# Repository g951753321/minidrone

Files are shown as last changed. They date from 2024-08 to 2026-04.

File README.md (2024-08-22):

# Minidrone project

This project is a complex project that involves the firmware development, the schematic, and PCB design for a mini drone.

## Firmware development

The firmware development is done using the Zephyr RTOS. The firmware includes the control algorithms for the drone, and the communication with the MicroBlue application.

### Setup Zephyr RTOS

To setup the Zephyr RTOS, follow the instructions in the [Zephyr RTOS documentation](https://docs.zephyrproject.org/latest/getting_started/index.html).

### Project Initialization

To initial the project, clone the repository and run the following commands:

```bash
west init -m https://github.com/g951753321/minidrone.git --mr main minidrone
cd minidrone
west update
```

### Build the project

To build the project, run the following commands:

```bash
west build -b stm32_dev_min minidrone/apps/PID_control
```

The firmware is built for the `stm32_dev_min` board, and the application is `PID_control`.
The output files are located in the `build/zephyr` directory.

## Schematic and PCB design

The schematic/PCB design is done using KiCad. The schematic includes the design of the motor drivers, the microcontroller, and the sensors.

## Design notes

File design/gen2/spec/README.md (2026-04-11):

# miniDrone Gen 2 — Specification Summary

## At a Glance

| Parameter | Value |
|---|---|
| Frame | Quadrotor X-config, 200 x 200 mm max (excl. props) |
| Battery | 3S LiPo (CNHL MiniStar 850mAh 70C) |
| Motors | Brushless 1404 4500KV |
| Propellers | 3 inch |
| Flight Controller | STM32H743VIH6 (Cortex-M7, 480 MHz, FPU-DP) |
| IMU | ICM-42688-P (SPI, 32 kHz, on-PCB center) |
| RC Link | ExpressLRS 2.4 GHz (CRSF, 2-5 ms latency) |
| Config Link | BLE 5.0 (nRF52832 module, phone app) |
| Architecture | Core Module (40x25mm) + Carrier Board (50x50mm)|
| Connector | Castellated pads, 1.27mm pitch, 2x30-pin per edge |
| FW Framework | Zephyr RTOS |

## Specifications

| Parameter | Value |
|---|---|
| Motor | 1404 / 4500 KV  |
| Battery | CNHL 3S 850mAh 70C |
| Pack Voltage | 9.0 - 12.6V |
| AUW | 141 g |
| Max Thrust | 800 g |
| Thrust / Weight | 5.7 : 1 |
| Max Payload | ~100 g (T/W 3.3:1) |
| Hover Time | ~26 min |
| Mixed Flight Time | ~18 min |
| Charging | External balance charger |
| Optional Modules | GPS (2.8g), Camera/VTX (4.5-7g) |

## Sensor Suite

| Sensor | IC | Bus  | Purpose |
|---|---|---|---|
| IMU | ICM-42688-P | SPI1 | Attitude (accel + gyro) |
| Barometer | BMP390 | I2C1 | Altitude hold (> 2 m) |
| Time-of-Flight | VL53L5CX | I2C1 | Altitude hold (< 4 m) |
| Optical Flow | PMW3901 | SPI2 | Position hold |
| Pack ADC | STM32 ADC1  | -- | Pack voltage (30K/10K divider) |
| Cell ADC | STM32 ADC1  | -- | Per-cell voltage via JST-XH balance port |
| Motor Current  | Shunt+OpAmp | ADC3 | Backup stall detect |
| Motor RPM | DSHOT bidir | TIM1 | Per-motor eRPM via bidirectional DSHOT300 |

## Control Architecture

```mermaid
graph TD
    ELRS["ELRS RX<br/>(CRSF 420kbaud)"] --> CP["CRSF Parser"]
    BLE["BLE Module<br/>(115200 baud)"] --> BP["BLE Protocol Parser"]
    CP --> CD["Command Dispatch<br/>(drone_cmd_t)"]
    BP --> CD
    CD --> SM["State Machine<br/>[Calibrate | Diag | Running | Error]"]
    SM --> APID["Angle PID<br/>(1 kHz)"]
    SM --> AltPID["Altitude PID<br/>(50 Hz)"]
    SM --> PosPID["Position PID<br/>(50 Hz)"]
    AltPID --> APID
    PosPID --> APID
    APID --> RPID["Rate PID<br/>(4 kHz)"]
    RPID --> MIX["Motor Mixer"]
    MIX --> DSHOT["DSHOT300 DMA"]
    DSHOT --> M1["M1 FR"]
    DSHOT --> M2["M2 FL"]
    DSHOT --> M3["M3 BR"]
    DSHOT --> M4["M4 BL"]

    IMU["ICM-42688-P<br/>(SPI, 8 kHz)"] --> RPID
    IMU --> APID
    BARO["BMP390<br/>(I2C, 50 Hz)"] --> AltPID
    TOF["VL53L5CX<br/>(I2C, 60 Hz)"] --> AltPID
    OF["PMW3901<br/>(SPI, 100 Hz)"] --> PosPID
```

## Power Architecture

```mermaid
graph LR
    subgraph CARRIER ["Carrier Board"]
        BAT["Battery<br/>3S LiPo<br/>(XT60)"] --> PTC["PTC Fuse<br/>5A / 10A"]
        PTC --> PFET["P-FET Switch<br/>DMP3010LK3<br/>30V"]
        PFET --> LC["LC Filter<br/>4.7uH + 100uF"]
        LC --> VBAT["+VBAT<br/>(ESC / Motors)"]
        LC --> BUCK["TPS63070<br/>Buck<br/>6-13V → 3.3V"]
        BAL["Balance Port<br/>JST-XH"] -.->|"cell taps"| ADC["MCU ADC<br/>cell monitoring"]
        BAL -.->|"external balance charger"| BAT
    end

    subgraph CORE ["Core Module"]
        USB["USB-C<br/>VBUS 5V"] --> ESD["TVS ESD<br/>USBLC6"]
        ESD --> LDO["AP2112K LDO<br/>5V → 3.3V"]
        ESD --> USBPHY["STM32 USB<br/>DFU / CDC"]
        LDO --> PWROR["Power OR"]
        PWROR --> V33["+3V3<br/>(All Digital)"]
    end

    BUCK -->|"carrier 3V3<br/>(via castellated pads)"| PWROR
```

## State Machine

```mermaid
stateDiagram-v2
    [*] --> Calibrate : Power On

    Calibrate --> Diag : success
    Calibrate --> Calibrate : fail (retry)
    Calibrate --> Error : timeout / HW fault

    Diag --> Running : arm (pre-flight pass)
    Diag --> Calibrate : recalibrate cmd

    Running --> Diag : disarm
    Running --> Diag : ELRS failsafe (500 ms)
    Running --> Diag : IMU failure (10 ms)
    Running --> Diag : battery critical
    Running --> Diag : excessive tilt > 60°
    Running --> Diag : motor stall

    Error --> [*] : watchdog reset
```

## Failsafe Summary

| Trigger | Detection Time | Motor Action |
|---|---|---|
| ELRS link loss | 500 ms | Ramp down 200 ms |
| IMU failure | 10 ms | Ramp down 200 ms |
| Battery critical | Per-cell < 3.3V| Ramp down 200 ms |
| Battery cutoff | Per-cell < 3.0V| Immediate off |
| Excessive tilt > 60°  | Immediate | Immediate off |
| Motor stall/overcurrent| 100 ms | Immediate off |

## Gen 1 Issues — All Resolved

| # | Issue | Gen 2 Resolution |
|---|---|---|
| HW-01 | Missing gate pull-downs  | ESC handles gate drive |
| HW-02 | No reverse polarity | P-FET (DMP3010LK3, 30V) |
| HW-03 | No overcurrent | PTC fuse (5A hold / 10A trip) |
| HW-04 | No LC filter | 4.7 uH + 100 uF on battery input |
| HW-05 | No gate resistors | ESC handles internally |
| HW-06 | No ESD protection | TVS on USB-C and SWD |
| HW-07 | DRC violations | 4-layer PCB resolves routing/thermal |
| HW-08 | IMU/BT power sequence | Separate enable; 200 ms delay |
| HW-09 | BOOT0 jumper usability | USB-C DFU via button hold |
| HW-10 | Cannot power off | High-side P-FET clean cutoff |
| HW-11 | Overweight (74 g) | 52-83 g (config dependent, all flyable)  |
| HW-12 | BT/IMU EMI interference  | IMU at center, BLE at edge, GND plane |
| HW-13 | LDO inefficient (45%) | TPS63070 buck-boost on carrier board (88-93%) |

## Purity Boundary

```mermaid
graph LR
    subgraph IN ["Input Shell"]
        CRSF_BE["CRSF Backend<br/>(UART)"]
        BLE_BE["BLE Backend<br/>(UART)"]
        SPI_DRV["SPI Drivers<br/>(IMU, Flash, OF)"]
        I2C_DRV["I2C Drivers<br/>(Baro, ToF)"]
        ADC_HAL["ADC HAL<br/>(Battery, Current)"]
    end

    subgraph CORE ["Pure Core"]
        CRSF_P["CRSF Parser"]
        BLE_P["BLE Parser"]
        CMD["Command Dispatch"]
        SM["State Machine"]
        APID["Angle PID"]
        RPID["Rate PID"]
        MIX["Motor Mixer"]
        ATT["Attitude Est."]
        ALT["Altitude Est."]
        POS["Position Est."]
        BATT["Battery Level"]
        DS_ENC["DSHOT Encoder"]
    end

    subgraph OUT ["Output Shell"]
        DSHOT_HAL["DSHOT DMA"]
        LED_HAL["WS2812B"]
        BB_LOG["Blackbox Flash"]
        USB_DRV["USB CDC/DFU"]
        TELEM["BLE Telemetry"]
    end

    CRSF_BE --> CRSF_P
    BLE_BE --> BLE_P
    SPI_DRV --> ATT
    SPI_DRV --> POS
    I2C_DRV --> ALT
    ADC_HAL --> BATT

    CRSF_P --> CMD
    BLE_P --> CMD
    CMD --> SM
    SM --> APID
    ALT --> APID
    POS --> APID
    ATT --> RPID
    APID --> RPID
    RPID --> MIX
    MIX --> DS_ENC

    DS_ENC --> DSHOT_HAL
    SM --> LED_HAL
    SM --> TELEM
    BATT --> TELEM
```

## Verification Strategy

| Tool | Target | Properties |
|---|---|---|
| **TLA+** | State machine | 13 safety + 4 liveness properties |
| **CBMC** | Pure core C code | 17 bounded model-check properties |
| **Fuzz** | CRSF + BLE parsers | Buffer safety, termination |
| **Ztest**| Full firmware | 20 testable-only properties |
| **HIL**  | Hardware-in-loop | Timing, accuracy, end-to-end |

## Key Design Decisions

1. **ELRS + BLE dual-link** — ELRS for low-latency flight; BLE for config/OTA. Independent.
2. **3S single config** — CNHL 850mAh 70C. Per-cell monitoring via JST-XH balance port.
3. **4-layer PCB** — GND plane fixes Gen 1 EMI; smaller board; ~$2-3 extra/board.
4. **Cascaded PID** — Angle (1 kHz) + rate (4 kHz), far better than Gen 1 single 500 Hz.
5. **Pure core / shell** — All flight math is deterministic, host-testable, formally verifiable.
6. **ICM-42688-P** — 10x lower noise than MPU6050, SPI, 32 kHz. MPU6050 is obsolete.
7. **TPS63070** — Buck regulator for 3S at ~89% efficiency; on carrier board.
8. **Modular core + carrier** — H743 dev module reusable for drones, robotics, and general embedded dev. Castellated pads for zero-weight production or socketed for development.
9. **Per-cell monitoring via JST-XH** — Standard balance connector enables per-cell ADC monitoring AND external balance charging. Imbalance detection refuses arm on damaged batteries.
10. **Bidirectional DSHOT300 + BlueJay** — Per-motor eRPM telemetry at 4 kHz. RPM-based stall detection, dynamic notch filtering, per-motor health monitoring.
11. **GPS + Camera removable** — JST-GH connectors for optional u-blox M10 GPS (2.8g) and HDZero/analog VTX (4.5-7g). Zero weight when not installed.

## Spec Documents

| Document | Contents |
|---|---|
| [features.md](features.md) | Modes, sensors, comms, UI, power, logging, OTA |
| [hardware.md](hardware.md) | MCU, all ICs, power system, PCB stackup |
| [protocols.md](protocols.md) | SPI, I2C, CRSF, BLE binary, DSHOT, USB, ADC |
| [performance.md](performance.md) | Control loops, power budget, flight time, CPU load |
| [safety.md](safety.md) | Protection circuits, failsafe, EMI, ESD, thermal |
| [behavioral.md](behavioral.md) | Invariants, mode contracts, startup, 50 edge cases |
| [mechanical.md](mechanical.md) | Frame, motors, battery, weight, connectors |
| [remote_controller.md](remote_controller.md)| ELRS TX/RX, BLE GATT, OTA update flow |
| [verification.md](verification.md) | 35 provable + 20 testable properties, TLA+/CBMC/Fuzz |

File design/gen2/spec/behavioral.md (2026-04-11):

# Behavioral Specification (Gen 2)

## 1. Behavioral Contract

### 1.1 System Invariants

These conditions must hold true at all times regardless of mode.

| ID | Invariant |
|---|---|
| INV-1 | Motors DSHOT output = 0 (disarmed) unless mode is Running AND armed |
| INV-2 | Battery voltage is sampled at least once per 100 ms |
| INV-3 | Per-cell voltage < 3.0V (cutoff) forces all motors off immediately (scaled by detected cell count) |
| INV-4 | IMU failure detected after 10 ms of no INT1 pulse; motors ramp to 0 over 200 ms, transition to Diag |
| INV-5 | Watchdog timer is refreshed every rate PID loop iteration |
| INV-6 | PID integrator is clamped to prevent windup (both rate and angle loops) |
| INV-7 | Motor DSHOT throttle value never exceeds 2047 |
| INV-8 | Motor current never exceeds 5 A per channel (software cutoff) |
| INV-9 | CRSF failsafe activates if no valid frame received within 500 ms |
| INV-10| Blackbox logging does not block flight-critical loops (async DMA writes) |

### 1.2 Mode Preconditions and Postconditions

#### Calibrate Mode

| Aspect | Contract |
|---|---|
| Precondition  | Drone is powered on; motors are disarmed |
| Precondition  | IMU responds to WHO_AM_I (0x75 = 0x47) |
| Precondition  | Barometer responds to CHIP_ID (0x00 = 0x60) |
| Invariant | Motors remain disarmed for entire duration |
| Postcondition (success) | IMU offsets stored; baro ground reference stored; transition to Diag |
| Postcondition (fail) | Error sent via BLE telemetry; remain in Calibrate; LED red blink |
| Postcondition (timeout) | 5 s timeout; calibration fails; report error |

#### Diag Mode

| Aspect | Contract |
|---|---|
| Precondition  | Calibration completed successfully (offsets valid) |
| Invariant | Motors disarmed unless single-motor test active |
| Invariant | Motor test duration <= 500 ms, one motor at a time |
| Postcondition (arm) | All pre-flight checks pass; transition to Running |
| Postcondition (recalib) | Clear stored offsets; transition to Calibrate |

##### Pre-Flight Checks (must all pass before arming)

| Check | Condition |
|---|---|
| Calibration valid | IMU offsets stored and non-zero |
| Battery sufficient | Per-cell voltage >= 3.3V (above critical)|
| Cells balanced | max-min cell delta < 100 mV |
| ELRS link active | Valid CRSF frame within last 500 ms |
| IMU healthy | INT1 pulses within last 10 ms |
| ESC RPM telemetry alive  | All 4 motors responding to bidir DSHOT (or backup current sense OK) |
| Throttle low | CRSF CH3 < 200 (near minimum) |
| Arm switch off then on | CH5 must transition from disarm to arm |
| Drone level | Tilt < 10 deg from horizontal |

#### Running Mode

| Aspect | Contract |
|---|---|
| Precondition  | All pre-flight checks passed |
| Precondition  | Battery per-cell voltage >= 3.3V (above critical) |
| Precondition  | ELRS link active |
| Invariant | Rate PID loop executes at 4 kHz (+/- 2%) |
| Invariant | Angle PID loop executes at 1 kHz (+/- 5%) |
| Invariant | CRSF stick center produces zero pitch/roll/yaw setpoint |
| Invariant | Throttle minimum produces motor idle (DSHOT 48); PID active |
| Postcondition (disarm)  | Motors ramp to 0 over 200 ms; PID reset; → Diag  |

#### Error Mode

| Aspect | Contract |
|---|---|
| Precondition  | Unrecoverable fault detected (IMU absent, flash corrupt, etc.)|
| Invariant | Motors permanently disarmed |
| Invariant | LED red fast blink |
| Postcondition | Watchdog timeout → MCU reset → retry startup |

### 1.3 Startup Sequence Contract

```
1.  MCUboot validates active image in Slot 0 (signature + CRC)
    - If invalid: attempt swap with Slot 1 or enter DFU mode
2.  Application boots; start watchdog timer (IWDG, 100 ms timeout)
3.  Initialize GPIO (all DSHOT pins LOW; sensor load switch OFF)
4.  Initialize system clock (HSE 25 MHz → PLL1 → 480 MHz);
    configure D-Cache and I-Cache; configure MPU for DMA regions
5.  Initialize USB (CDC + DFU composite device)
6.  Initialize Zephyr shell (USB CDC + BLE NUS backends)
7.  Check SW1 button state:
    - Held > 3 s → enter DFU mode (no further init)
    - Double-press → enter ELRS bind mode (set flag, continue)
8.  Initialize USART1 (CRSF @ 420000 baud)
9.  Initialize USART2 (BLE NUS @ 115200 baud; shell transport active)
10. Start battery ADC + cell monitoring (DMA, 10 Hz)
10a. Validate 3S battery voltage:
     - 9.0-13.1V → 3S valid, continue
     - < 9.0V → no battery or depleted; USB-only power; refuse arm
11. **Enable sensor load switch** (TPS22918 GPIO HIGH); wait 100 ms
12. Initialize SPI1 (IMU); verify WHO_AM_I (up to 3 retries, 100 ms delay)
    - PASS → continue
    - FAIL → enter Error mode
13. Initialize I2C1; verify barometer (BMP390 CHIP_ID)
    - PASS → continue
    - FAIL → enter Error mode (baro required for auto-land)
14. Initialize SDMMC1 (MicroSD); mount FAT32 filesystem
    - FAIL → log warning; continue without blackbox
15. Initialize VL53L5CX (firmware upload, ~300 ms)
    - FAIL → log warning; continue without ToF (altitude hold degraded)
16. Initialize PMW3901 (Product_ID check)
    - FAIL → log warning; continue without OF (position hold disabled)
16a. Check for GPS module on UART4 (wait 2 s for NMEA sentence)
    - Detected → enable GPS features (outdoor position hold, RTH)
    - Not detected → GPS features disabled (no warning, optional module)
17. Call boot_write_img_confirmed() (MCUboot: mark firmware as valid)
17. Initialize flash (JEDEC ID check)
    - FAIL → log warning; continue without blackbox
18. Enter Calibrate mode
```

Note: Steps 15-17 are non-critical sensors. Failure degrades capability but
does not prevent flight. Steps 13-14 are mandatory.

### 1.4 Shutdown Contract

| Trigger | Behavior |
|---|---|
| SW2 power off | P-FET cuts power; no software action |
| Watchdog timeout | MCU reset → full startup sequence |
| Cell voltage < 3.0V  | Motors off immediately, remain in Diag |
| USB DFU mode | Flight disabled; USB active for firmware update |

---

## 2. Interface Definition

### 2.1 Abstract Input Interface

The drone consumes input through an abstract interface, decoupled from any
specific transport. The primary backend is CRSF over ELRS; the secondary is
BLE for configuration commands.

#### Input Commands (Transport-Agnostic)

| Command | Parameters | Valid In |
|---|---|---|
| CMD_ARM | -- | Diag |
| CMD_DISARM | -- | Running |
| CMD_CALIBRATE | -- | Diag |
| CMD_STICK | throttle, yaw, pitch, roll (int16 each) | Running |
| CMD_SET_FLIGHT_MODE| mode (ACRO / ANGLE / ALT_HOLD) | Running |
| CMD_POSITION_HOLD  | enable (bool) | Running |
| CMD_SET_PID_GAIN | loop (RATE/ANGLE), axis (P/R/Y), gain (KP/KI/KD), value (float) | Any |
| CMD_MOTOR_TEST | motor_id (0-3) | Diag |
| CMD_FIND_ME | enable (bool) | Diag |
| CMD_BLACKBOX_DL | offset, length | Diag |
| CMD_BLACKBOX_ERASE | -- | Diag |

#### Input Command Struct

```c
typedef enum {
    CMD_ARM,
    CMD_DISARM,
    CMD_CALIBRATE,
    CMD_STICK,
    CMD_SET_FLIGHT_MODE,
    CMD_POSITION_HOLD,
    CMD_SET_PID_GAIN,
    CMD_MOTOR_TEST,
    CMD_FIND_ME,
    CMD_BLACKBOX_DL,
    CMD_BLACKBOX_ERASE,
} cmd_type_t;

typedef enum {
    FLIGHT_MODE_ACRO,
    FLIGHT_MODE_ANGLE,
    FLIGHT_MODE_ALT_HOLD,
} flight_mode_t;

typedef enum {
    PID_LOOP_RATE,
    PID_LOOP_ANGLE,
} pid_loop_t;

typedef enum {
    PID_AXIS_PITCH,
    PID_AXIS_ROLL,
    PID_AXIS_YAW,
} pid_axis_t;

typedef enum {
    GAIN_KP,
    GAIN_KI,
    GAIN_KD,
} gain_type_t;

typedef struct {
    cmd_type_t type;
    union {
        struct { int16_t throttle; int16_t yaw;
                 int16_t pitch; int16_t roll; }          stick;
        struct { flight_mode_t mode; }                    flight_mode;
        struct { bool enable; }                           position_hold;
        struct { pid_loop_t loop; pid_axis_t axis;
                 gain_type_t gain; float value; }         pid_gain;
        struct { uint8_t motor_id; }                      motor_test;
        struct { bool enable; }                           find_me;
        struct { uint32_t offset; uint32_t length; }      blackbox_dl;
    };
} drone_cmd_t;
```

#### CRSF Backend Mapping

CRSF channels are mapped to `drone_cmd_t` as follows. For channel assignment
details, see [remote_controller.md](remote_controller.md#channel-assignment-edgetx-mixer).
For CRSF frame format and CRC, see [protocols.md](protocols.md).

| CRSF Input | drone_cmd_t |
|---|---|
| CH1-CH4 (sticks) | CMD_STICK { map(172..1811 → signed range) } |
| CH5 (AUX1) low→high | CMD_ARM |
| CH5 (AUX1) high→low | CMD_DISARM |
| CH6 (AUX2) 3-pos | CMD_SET_FLIGHT_MODE { ACRO / ANGLE / ALT_HOLD }|
| CH7 (AUX3) | CMD_POSITION_HOLD { on/off } |
| CH8 (AUX4) | CMD_FIND_ME { on/off } |

#### BLE Backend Mapping

BLE commands use the binary protocol defined in [protocols.md](protocols.md#ble-communication-protocol).
BLE handles configuration commands only (not flight-critical):

| BLE CMD  | drone_cmd_t |
|---|---|
| 0x10 | CMD_SET_PID_GAIN { loop, axis, gain, value } |
| 0x11 | CMD_BLACKBOX_DL { offset, length } |
| 0x12 | CMD_BLACKBOX_ERASE |
| 0x13 | CMD_FIND_ME { enable } |

### 2.2 Abstract Output Interface (Telemetry)

| Telemetry | Parameters | Rate | Mode |
|---|---|---|---|
| TELEM_BATTERY | voltage_mv (uint16) | 1 Hz | All |
| TELEM_CALIB_RESULT | ok (bool) | Once | Calibrate |
| TELEM_IMU | ax,ay,az,gx,gy,gz (int16) | 10 Hz | Diag |
| TELEM_MODE | mode (enum) | On change  | All |
| TELEM_ERROR | error_code (enum) | On event | All |
| TELEM_LOW_BATT | level (WARNING/CRITICAL) | On change  | All |
| TELEM_ALTITUDE | altitude_cm (int32) | 10 Hz | Running |
| TELEM_LINK_STATS | rssi (int8), lq (uint8) | 1 Hz | All |
| TELEM_MOTOR_CURRENT  | current_mA[4] (uint16) | 10 Hz | Running |

Telemetry is sent via two backends simultaneously:
- **BLE**: all telemetry types (for phone app / configurator)
- **CRSF uplink**: battery voltage, attitude, flight mode (for TX OSD display)

### 2.3 Internal Interfaces

#### IMU Driver

| Function | Input | Output | Rate |
|---|---|---|---|
| imu_init() | -- | status (OK / FAIL) | Once |
| imu_read() | -- | ax,ay,az,gx,gy,gz (int16, raw)  | 8 kHz |
| imu_calibrate()  | sample_count | offsets[6] (int16) | Once |
| imu_health() | -- | bool (INT1 received within 10 ms)| On demand|

#### Motor Driver

| Function | Input | Output  | Constraint |
|---|---|---|---|
| motor_set_dshot()  | channel (0-3), throttle (uint16) | -- | throttle <= 2047 |
| motor_all_stop() | -- | -- | Send DSHOT 0 to all |
| motor_ramp_down()  | duration_ms | -- | Async, non-blocking |
| motor_arm_sequence()| -- | -- | DSHOT arm handshake |
| motor_get_rpm() | ch(0-3) | uint16 RPM | From bidir DSHOT eRPM |

#### Battery Monitor (Pack + Per-Cell)

| Function | Input  | Output | Rate |
|---|---|---|---|
| battery_read_pack_mv()| -- | pack voltage in mV (uint16) | 10 Hz |
| battery_read_cell_mv()| cell(0-2)| cell voltage in mV (uint16) | 10 Hz |
| battery_level() | -- | NORMAL/WARNING/CRITICAL/CUTOFF | 10 Hz |
| battery_imbalance_mv()| -- | max_cell - min_cell delta (uint16) | 10 Hz |
| battery_cell_count()  | -- | 1, 2, or 3 (detected at boot) | Once |

#### Motor Health Monitor

| Function | Input  | Output | Rate |
|---|---|---|---|
| motor_current_mA() | ch(0-3)| current in mA (uint16) | 1 kHz |
| motor_stall_check()  | -- | stall_detected (bool) | 100 Hz (RPM-based primary, current backup) |

#### PID Controller (Cascaded)

Rate loop (inner): 3 independent instances (pitch_rate, roll_rate, yaw_rate)
Angle loop (outer): 2 independent instances (pitch_angle, roll_angle)

| Function | Input | Output |
|---|---|---|
| pid_rate_update() | setpoint, gyro_rate, dt | control output (float) |
| pid_angle_update() | setpoint, estimated_angle, dt  | rate setpoint (float) |
| pid_set_gains() | loop, axis, Kp, Ki, Kd | -- |
| pid_reset() | -- | Clear integrator + derivative state |

#### Attitude Estimator

| Function | Input | Output |
|---|---|---|
| attitude_update() | accel[3], gyro[3], dt | pitch, roll, yaw (float, deg) |

Uses complementary filter (alpha = 0.98 gyro, 0.02 accel).
Future: upgrade to Madgwick or Mahony AHRS.

#### Altitude Estimator

| Function | Input | Output |
|---|---|---|
| altitude_update() | baro_pa, tof_mm, dt | altitude_cm (int32)  |

Fusion: ToF used below 2 m (high accuracy); barometer used above 2 m.
Crossfade between 1.5 m and 2.5 m.

#### Position Estimator

| Function | Input | Output |
|---|---|---|
| position_update() | flow_dx, flow_dy, altitude, dt | velocity_x, velocity_y (float, cm/s) |

Optical flow delta scaled by altitude for metric velocity.

#### Motor Mixer

Converts throttle + PID outputs into four DSHOT throttle values.

```
        Front
    FL(CCW) --- FR(CW)
    |               |
    BL(CW)  --- BR(CCW)
         Back
```

| Motor | Ref | Rotation | Equation |
|---|-----|---|---|
| FR | M1  | CW | throttle + pitch_out + roll_out - yaw_out |
| FL | M2  | CCW | throttle + pitch_out - roll_out + yaw_out |
| BR | M3  | CCW | throttle - pitch_out + roll_out + yaw_out |
| BL | M4  | CW | throttle - pitch_out - roll_out - yaw_out |

Output clamping: each motor value clamped to [0, 2047].
Negative values after mixing are set to 0.

### 2.4 Command Acceptance Matrix

Commands received in an invalid mode are silently ignored.

| Command | Calibrate | Diag | Running | Error |
|---|---|---|---|---|
| CMD_ARM | ignore | accept | ignore | ignore |
| CMD_DISARM | ignore | ignore | accept | ignore |
| CMD_CALIBRATE | ignore | accept | ignore | ignore |
| CMD_STICK | ignore | ignore | accept | ignore |
| CMD_SET_FLIGHT_MODE  | ignore | ignore | accept | ignore |
| CMD_POSITION_HOLD | ignore | ignore | accept | ignore |
| CMD_SET_PID_GAIN | accept | accept | accept | ignore |
| CMD_MOTOR_TEST | ignore | accept | ignore | ignore |
| CMD_FIND_ME | ignore | accept | ignore | ignore |
| CMD_BLACKBOX_DL | ignore | accept | ignore | ignore |
| CMD_BLACKBOX_ERASE | ignore | accept | ignore | ignore |

---

## 3. Edge Case Catalog

### 3.1 Communication Edge Cases

| ID | Scenario | Expected Behavior |
|---|---|---|
| EC-01 | CRSF frame CRC mismatch | Frame discarded; use last valid channel data |
| EC-02 | CRSF frame too short (< 4 bytes) | Frame discarded |
| EC-03 | CRSF sync byte wrong | Resync: scan for next 0xC8 |
| EC-04 | CRSF link lost during Running (alt < 2 m) | Failsafe after 500 ms; ramp motors down; → Diag |
| EC-04a| CRSF link lost during Running (alt >= 2 m) | Failsafe after 500 ms; enter AUTO_LAND: descend 0.5 m/s, hold position (OF/GPS), land when ToF < 0.1 m; → Diag |
| EC-05 | CRSF link restored during AUTO_LAND | Hold altitude; wait for user stick input; resume manual control |
| EC-05a| CRSF link restored after landing complete  | Remain in Diag; user must re-arm |
| EC-06 | ELRS packet rate change mid-flight | Transparent: CRSF parser handles variable rates |
| EC-07 | BLE disconnect during Running | No flight action (BLE not flight-critical) |
| EC-08 | BLE and CRSF send conflicting commands | CRSF has priority for flight commands; BLE for config only |
| EC-09 | UART receive buffer overflow (CRSF) | DMA circular buffer; oldest data overwritten; parser resyncs |
| EC-10 | Rapid arm/disarm toggle | 1 s cooldown between arm attempts |
| EC-11 | BLE protocol checksum mismatch | Frame discarded; NACK sent |

### 3.2 Sensor Edge Cases

| ID | Scenario | Expected Behavior |
|---|---|---|
| EC-12 | IMU WHO_AM_I returns wrong ID at boot | Enter Error mode; LED red blink |
| EC-13 | IMU SPI bus error (MISO stuck) | SPI timeout (5 ms); retry 3x; if fail: failsafe |
| EC-14 | IMU data spike (single-sample outlier) | Handled by digital filter (ICM-42688 AAF + firmware LPF) |
| EC-15 | Calibration with drone not level | Offsets will be wrong; user must recalibrate |
| EC-16 | Calibration with drone moving | Variance check; stddev > threshold → fail |
| EC-17 | IMU failure during Running | Detected after 10 ms no INT1; ramp motors down; → Diag |
| EC-18 | Barometer fails during flight | Altitude hold disabled; degrade to angle/acro mode; warn user |
| EC-19 | ToF out of range (> 4 m) | ToF data marked invalid; altitude from baro only |
| EC-20 | Optical flow over featureless surface | SQUAL < 20; position hold disabled; warn user |
| EC-21 | Optical flow fails completely | Position hold disabled; altitude hold still works |

### 3.3 Power Edge Cases

| ID | Scenario | Expected Behavior |
|---|---|---|
| EC-22 | Battery voltage drops below 3.3V (critical) | LED red blink; buzzer rapid; auto-disarm |
| EC-23 | Battery voltage drops below 3.0V (cutoff) | Motors off immediately; remain in Diag |
| EC-24 | Battery voltage recovers above threshold | No auto-transition; user must re-arm manually |
| EC-25 | ADC noise near threshold | Hysteresis: 100 mV gap between enter and exit |
| EC-26 | Battery disconnected while running | Hardware power loss; no software action possible |
| EC-27 | USB connected during flight | USB powers core module only; flight unaffected |
| EC-28 | USB VBUS without battery | Core module powered from USB; motors disabled (no battery = cannot arm) |
| EC-28a| Battery voltage < 6.0V at boot | Treated as no battery or critically depleted; refuse arm |
| EC-28b| Cell imbalance > 100 mV at boot | Refuse arm; warn user; recommend rebalance via external charger |
| EC-28c| Cell imbalance > 200 mV in flight | Critical: ramp motors to 0; → Diag; log event |
| EC-28d| Single cell drops below 3.0V (cutoff) | Motors off immediately; → Diag (even if pack avg > cutoff) |
| EC-28e| Balance connector unplugged (only main connected) | Cell readings = 0 or noise; firmware detects and disables cell-based protection; falls back to pack-only monitoring with warning |

### 3.4 Motor Edge Cases

| ID | Scenario | Expected Behavior |
|---|---|---|
| EC-29 | Motor test held in Diag | Single pulse 500 ms max; ignore until command released |
| EC-30 | Multiple motor test simultaneous | Only first received honored; others ignored |
| EC-31 | Full throttle immediately after arm | Throttle must be low to arm (pre-flight check); after arm, rate limiter: max 100 DSHOT/tick |
| EC-32 | Throttle zero while armed | Motors at idle (DSHOT 48); PID stabilization active  |
| EC-33 | Excessive tilt (> 60 deg) | Motors off immediately; → Diag |
| EC-34 | Motor stall (eRPM = 0 with throttle > 200) | Disarm all motors; → Diag; report error |
| EC-35 | Motor overcurrent (> 5 A) | Affected motor DSHOT = 0; disarm all; → Diag |
| EC-36 | ESC desync (eRPM > 30% off expected) | BlueJay handles internally; FC logs event; if persistent > 200 ms, warn user |
| EC-37 | Prop strike / sudden load | Detected via RPM drop + current spike; if persistent, disarm |
| EC-37a| Bidirectional DSHOT response timeout | Mark motor as no-telemetry; fall back to current sensing for stall detection |
| EC-37b| GCR decode CRC error | Discard reading; use last valid eRPM; counter triggers fallback if persistent |
| EC-37c| All 4 motors lose RPM telemetry | ESC firmware fault: disarm; → Diag; report error |

### 3.5 Mode Transition Edge Cases

| ID | Scenario | Expected Behavior |
|---|---|---|
| EC-38 | Arm with invalid calibration | Reject arm; remain in Diag; send error |
| EC-39 | Arm with low battery (< 3.3V per cell) | Reject arm; remain in Diag |
| EC-39a| Arm with cell imbalance > 100 mV | Reject arm; remain in Diag; suggest recharge |
| EC-40 | Arm with no ELRS link | Reject arm; remain in Diag |
| EC-41 | Arm with throttle not at minimum | Reject arm; remain in Diag |
| EC-42 | Arm with drone tilted > 10 deg | Reject arm; remain in Diag |
| EC-43 | Calibrate during Running | Ignore command |
| EC-44 | DFU mode requested during Running | Ignore (DFU only at boot via SW1) |
| EC-45 | Power on with critical battery (< 3.3V) | Complete startup; enter Diag; refuse arm |
| EC-46 | Flight mode switch during aggressive maneuver| Smooth transition: angle/rate setpoints interpolated over 100 ms |

### 3.6 Blackbox / Flash Edge Cases

| ID | Scenario | Expected Behavior |
|---|---|---|
| EC-47 | Flash full during flight | Circular buffer: overwrite oldest sector |
| EC-48 | Flash write error | Retry once; if fail, disable logging; flight continues |
| EC-49 | Flash erase during flight | Reject: erase only allowed in Diag mode |
| EC-50 | BLE blackbox download during flight | Reject: download only in Diag mode |

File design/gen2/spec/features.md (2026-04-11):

# Feature Specification (Gen 2)

## Design Constraints

| Parameter | Value |
|---|---|
| Body Size Limit | 200 mm (W) x 200 mm (L), excluding propellers |
| Target AUW | 141 g — see [mechanical.md](mechanical.md) |
| Target Flight Time | ~26 min hover |
| Battery | 3S LiPo (CNHL MiniStar 850mAh 70C) |
| Use Environment | Indoor / Outdoor |
| Architecture | Core Module (40x25mm) + Carrier Board (50x50mm) |

## Modular Architecture

The system is split into a reusable **Core Module** and a drone-specific **Carrier Board**.

### Core Module (40 x 25 mm)
- STM32H743VIH6 MCU (Cortex-M7, 480 MHz, 2 MB flash, 1 MB SRAM)
- nRF52832 BLE 5.0 module
- USB-C (DFU, CDC serial, standalone power)
- SWD debug header
- Reset + DFU buttons, power LED, WS2812B status LED
- Can operate standalone (powered from USB) for development

### Carrier Board (50 x 50 mm, drone-specific)
- All flight sensors (IMU, baro, ToF, optical flow)
- ELRS receiver pads
- ESC / motor pads
- Battery management (TPS63070, charger, protection)
- Buzzer, companion computer header
- For hardware details, see [hardware.md](hardware.md)

### Core Module as Dev Board
The core module functions as a standalone development board:
- Plug into USB-C, program via DFU or SWD
- All MCU peripherals exposed on 1.27mm castellated edge pads
- BLE available for wireless debug and configuration
- Design custom carrier boards for other applications (robotics, data loggers, etc.)

## Operating Modes

The drone operates in four distinct modes, transitioned via ELRS command,
BLE command, or hardware button (SW1).

### Mode Overview

| Mode | Purpose | Motors | LED Color |
|---|---|---|---|
| Calibrate | IMU + barometer offset calibration | Off | Yellow breathe |
| Diag | Sensor readout and system check | Off | Blue solid |
| Running | Active flight with PID control | Armed  | Green solid |
| Error | Unrecoverable fault | Off | Red fast blink |

### Mode: Calibrate

Entered on first boot or by user command. The drone must be placed on a flat,
level surface and remain still during calibration.

- Collect N samples of accelerometer, gyroscope, and barometer data
- Compute and store zero-offset for each IMU axis
- Store barometer ground-level reference pressure
- Send calibration result via telemetry (`"calib"`, `"ok"` / `"fail"`)
- Auto-transition to Diag mode on success

### Mode: Diag

Diagnostic mode for pre-flight system verification. Motors remain disarmed.

- Stream live IMU data via telemetry for inspection
- Report battery voltage and cell count
- Verify ELRS link quality (RSSI, LQ)
- Verify BLE link status
- Verify optical flow sensor status
- Verify barometer / ToF altitude sensor status
- Individual motor test via command (brief DSHOT pulse, one at a time)
- Transition to Running mode via arm command
- Transition to Calibrate mode via calibrate command

### Mode: Running

Active flight mode with cascaded PID stabilization loop.

- Cascaded PID: outer angle loop + inner rate loop, active at 1 kHz (rate) / 500 Hz (angle)
- ELRS stick inputs mapped to throttle / yaw / pitch / roll
- Altitude hold mode via barometer + ToF fusion (toggle via AUX channel)
- Position hold mode via optical flow (toggle via AUX channel)
- PID gains adjustable via BLE configuration interface
- Low battery critical: ramp motors to 0 over 200 ms, transition to Diag
- Disarm command transitions back to Diag mode
- **ELRS failsafe auto-land**: if altitude > 2 m, descend at 0.5 m/s and land; if < 2 m, ramp motors to zero. See [safety.md](safety.md#failsafe-conditions)

### Mode: Error

Entered on unrecoverable hardware fault (IMU not detected, flash corrupt, etc.).

- All motors off
- RGB LED red fast blink
- Error code sent via BLE telemetry
- Watchdog timeout resets MCU to retry startup sequence

### State Transitions

```
                   Power On
                      |
                      v
               +-----------+
               | Calibrate |<-----+
               +-----------+      |
                  |  success      | recalibrate cmd
                  |               |
                  |  fail/timeout |
                  |------+        |
                  v      v        |
               +------+ +-------+ |
          +--->| Diag |  | Error | |
          |    +------+--+-------+ |
          |       | arm cmd       |
          |       v               |
          |  +---------+          |
          +--| Running |----------+
   disarm    +---------+
   low batt
   ELRS failsafe
   IMU failure
   excessive tilt
```

## Flight Control

- 4-channel brushless motor control via DSHOT300
- Cascaded PID attitude stabilization (angle + rate loops)
- 6-axis IMU sensor fusion (accelerometer + gyroscope, ICM-42688-P)
- Barometric altitude hold (BMP390 + VL53L5CX fusion)
- Optical flow position hold (PMW3901)
- Configurable PID gain tuning via BLE
- Motor current sensing via shunt resistor + external op-amp on carrier

## Sensors

| Sensor | IC / Module | Interface | Purpose |
|---|---|---|---|
| IMU | ICM-42688-P | SPI1 | Attitude (accel + gyro) |
| Barometer | BMP390 | I2C1 | Altitude hold (> 2 m) |
| Time-of-Flight | VL53L5CX | I2C1 | Altitude hold (< 4 m) |
| Optical Flow | PMW3901 | SPI2 | Position hold |
| Battery ADC | STM32H7 ADC1  | Internal  | Voltage via divider (30K/10K) |
| Motor Current  | Shunt + op-amp| ADC2 | Stall / overcurrent detect |

For IC specifications and placement requirements, see [hardware.md](hardware.md).
For bus protocols and register maps, see [protocols.md](protocols.md).

## Communication

| Link | Purpose | Module / Interface |
|---|---|---|
| ELRS 2.4 GHz | Primary flight control | ELRS Lite RX, UART (CRSF)|
| BLE 5.0 | Config, telemetry, OTA | nRF52832 module (MDBT42Q) |
| USB-C | Programming, debug, charge| STM32H7 native USB 2.0 FS|
| SWD | Debug interface | 4-pin header (SWDIO, SWCLK, GND, 3V3) |

## User Interface

| Component | Type | Purpose |
|---|---|---|
| RGB LED | WS2812B (x1) | Mode / status / battery indicator |
| Buzzer | Passive piezo | Arm beep, low battery alarm, lost model beep |
| Push Button | SW1 (tactile) | Mode cycle / bind / DFU boot |
| Power Switch | SW2 (slide) | Main power on/off |

### RGB LED Behavior per Mode

| Mode | Color | Pattern |
|---|---|---|
| Calibrate | Yellow | Breathe (fade in/out)|
| Diag | Blue | Solid on |
| Running | Green | Solid on |
| Error | Red | Fast blink (5 Hz) |
| Low Batt Warning  | Orange | Blink (2 Hz) |
| Low Batt Critical | Red | Blink (2 Hz) |
| ELRS not linked | Purple| Slow blink (1 Hz) |
| BLE connected | Cyan  | Single flash on connect |

### Buzzer Behavior

| Event | Pattern |
|---|---|
| Arm | Rising two-tone beep |
| Disarm | Falling two-tone beep |
| Low battery warning | Single beep every 2 s |
| Low battery critical| Continuous rapid beep |
| Lost model (BLE cmd)| Loud continuous tone |
| ELRS bind mode | Repeating short beep |

## Power Management

- **3S LiPo** (CNHL MiniStar 850mAh 70C) with per-cell monitoring via JST-XH
- **Cell imbalance detection**: refuse arm if max-min cell delta > 100 mV
- Per-cell threshold scaling (warning, critical, cutoff) — see [safety.md](safety.md)
- Per-motor RPM monitoring (bidirectional DSHOT) + current backup — see [safety.md](safety.md)
- Low battery warning (LED + buzzer + telemetry notification)
- **No onboard charger** — use external balance charger via JST-XH connector
- **GPS** (removable): JST-GH connector for u-blox M10 module — see [hardware.md](hardware.md)
- **Camera / VTX** (removable): power pads + UART for HDZero, analog, or ESP32-CAM — see [hardware.md](hardware.md)
- For power system components, see [hardware.md](hardware.md#power-supply)

## Programming and Debug

| Interface | Connector | Signals |
|---|---|---|
| USB-C | On core module | USB D+, D-, VBUS, CC1, CC2, GND |
| SWD | On core module (4-pin, 1.27mm pitch) | SWDIO, SWCLK, GND, 3V3 |

### Boot Modes

| SW1 Press at Power-On | Mode |
|---|---|
| Not pressed | Normal boot (flash) |
| Held > 3 s | USB DFU bootloader mode |
| Double-press | ELRS bind mode |

## Data Logging (Blackbox)

- **MicroSD card** (FAT32, SDMMC1 4-bit SDIO interface on carrier)
- File format: CSV (human-readable, directly openable in Linux/Excel/Python)
- Each flight creates a new file: `LOG00001.CSV`, `LOG00002.CSV`, etc.
- Logs: timestamp, IMU raw, PID outputs, motor RPM, battery/cell voltage, ELRS inputs
- Log rate: configurable 100 Hz - 1 kHz (~100 KB/s at 1 kHz)
- **Pop out SD card → plug into any PC → read files directly**
- Ring buffer in DTCM (32 KB) absorbs SD write latency spikes; PID loop unaffected
- Erase / format via BLE shell command or USB serial
- Storage: 8 GB card = ~22 hours at 1 kHz (effectively unlimited)

## OTA Firmware Update (MCUboot)

- **MCUboot** secure bootloader with dual-bank swap on H743
- Slot 0 (Bank 1): active firmware; Slot 1 (Bank 2): staging area
- OTA image received via BLE DFU → written to Slot 1 → MCUboot validates + swaps
- **Automatic rollback**: if new firmware crashes before calling `boot_write_img_confirmed()`, watchdog fires and MCUboot reverts to previous image
- Cryptographic validation: SHA-256 + ECDSA image signature
- Fallback: USB-C DFU mode via hardware button hold at boot
- For detailed OTA flow, see [remote_controller.md](remote_controller.md#ota-firmware-update-via-ble)

## BLE Shell (Runtime Command Line)

- **Zephyr shell over BLE NUS** (Nordic UART Service) via nRF52 module
- Connect from any BLE terminal app (nRF Connect, BLESerial nRF, Wible)
- Full command-line interface for runtime configuration and diagnostics:
  - `pid show`, `pid set pitch kp 1.5` — PID tuning
  - `imu read`, `imu calibrate` — sensor diagnostics
  - `motor test 0`, `motor rpm` — motor testing
  - `battery cells` — per-cell voltage readout
  - `blackbox start`, `blackbox stop`, `blackbox erase` — log control
  - `config save`, `config load` — persistent configuration
  - `gps status` — GPS fix info (when GPS module installed)
- Also accessible via USB CDC serial (same Zephyr shell, wired)
- Supplements structured BLE GATT telemetry (shell for debug, GATT for app)

## Expansion

- I2C bus exposed on SWD connector (shared pins) for external sensors
- 2 spare GPIO pads on PCB edge for future use
- MicroSD stores user configuration and waypoint data alongside logs

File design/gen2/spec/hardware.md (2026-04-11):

# Hardware Specification (Gen 2)

## Modular Architecture

The Gen 2 design is split into two boards:

- **Core Module** — MCU, BLE, USB-C, power regulation, flash. Reusable across projects.
- **Carrier Board** — Sensors, ESC, ELRS, battery management. Drone-specific.

Connected via **2x 30-pin castellated pad headers at 1.27 mm pitch**.

```
+-------------------------------+
|       Core Module (40x25mm)   |
|  STM32H743  nRF52  USB-C     |
|  Flash  LDO  SWD  Buttons    |
|  [||||||||||||||||||||||||||] |  ← 2x30 castellated pads (each side)
+-------------------------------+
         ↕ 1.27mm headers (dev) or solder-down (production)
+-------------------------------+
|      Carrier Board (50x50mm)  |
|  IMU  Baro  ToF  OF  ELRS    |
|  ESC pads  Battery  LC filter |
|  LED  Buzzer  Companion hdr   |
+-------------------------------+
```

### Core-to-Carrier Connector

| Parameter | Value |
|---|---|
| Type | Castellated pads (dual-use) |
| Pitch | 1.27 mm |
| Pins | 2x 30-pin, dual-row, two edges = **120 pads total** |
| Dev Mode | Solder 1.27 mm pin headers onto module; plug into sockets on carrier (e.g., Samtec SSQ series) |
| Production Mode | Solder module directly to carrier via castellated pads |
| Mated Height (dev)  | ~8 mm (with socket) |
| Mated Height (prod) | 0 mm (flush solder) |

### Pin Allocation on Connector

| Group | Pins | Signals (exposed on castellated pads) |
|---|---|---|
| SPI1 | 4 | SCK, MISO, MOSI, CS1 |
| SPI2 | 4 | SCK, MISO, MOSI, CS2 |
| SPI4 | 4 | SCK, MISO, MOSI, CS3 |
| I2C1 | 2 | SDA, SCL |
| I2C2 | 2 | SDA, SCL |
| USART1 | 2 | TX, RX |
| USART3 | 2 | TX, RX |
| UART4 | 2 | TX, RX |
| UART7 | 2 | TX, RX |
| TIM1 CH1-4 | 4 | DSHOT / PWM outputs |
| TIM3 CH1-4 | 4 | Aux PWM outputs |
| ADC1 (x4) | 4 | Battery V, Cell1 V, Cell2 V, spare |
| ADC3 (x4) | 4 | Motor current x4 (via op-amps on carrier) |
| SDMMC1 | 7 | CK, CMD, D0-D3, CD (MicroSD on carrier) |
| Sensor Load Switch | 1 | GPIO output (TPS22918 enable) |
| EXTI (x6) | 6 | Interrupt-capable GPIO |
| GPIO (x10) | 10 | General purpose I/O |
| BLE USART2 TX/RX  | 2 | nRF52 passthrough (from core module) |
| nRF52 Reset | 1 | BLE module reset |
| USB D+/D- | 2 | USB passthrough (optional, if carrier needs connector) |
| +3V3 OUT | 4 | Regulated 3.3V from core module LDO |
| +VBAT IN | 4 | Battery voltage input to core module |
| GND | 16 | Ground (distributed for return current) |
| NRST | 1 | MCU reset |
| BOOT0 | 1 | Boot mode select |
| **Total** | **120** | |

## Core Module

### Microcontroller — STM32H743VIH6

| Parameter | Value |
|---|---|
| MCU | STM32H743VIH6 |
| Core | ARM Cortex-M7 (dual-issue, 6-stage pipeline) |
| FPU | **Double-precision** hardware FPU |
| Flash | **2 MB** (dual-bank) |
| SRAM | **1 MB** (DTCM 128K + AXI 512K + SRAM1-4) |
| I-Cache / D-Cache | 16 KB / 16 KB |
| Max Clock | **480 MHz** |
| Package | LQFP-100 (14 x 14 mm) |
| Operating Voltage | 1.62V - 3.6V |
| USB | USB 2.0 FS + **HS** (with internal PHY) |
| ADC | 3x **16-bit** 3.6 Msps |
| DAC | 2x 12-bit |
| Timers | Advanced (TIM1, TIM8), GP (TIM2-5, TIM12-17) |
| DMA | 2x DMA controller + MDMA |
| RNG | Hardware random number generator |

### Core Module Components

| Component | Part | Location |
|---|---|---|
| MCU | STM32H743VIH6 | Center |
| BLE Module | MDBT42Q (nRF52832) | Edge (antenna outward) |
| USB-C Connector | USB 2.0 receptacle | Edge |
| ESD Protection | USBLC6-2SC6 | Near USB-C  |
| LDO (module power) | AP2112K-3.3 (600mA) | Near MCU |
| HSE Crystal | 25 MHz (SMD 2520) | Near MCU |
| LSE Crystal | 32.768 kHz (SMD 3215) | Near MCU |
| SWD Header | 1x4 pin, 1.27mm pitch | Edge |
| Reset Button | Tactile (SW1) | Edge |
| Boot/DFU Button | Tactile (SW2) | Edge |
| Power LED | Green, 0402 | Edge |
| Status LED | WS2812B (x1) | Edge |
| Decoupling | Per STM32H743 datasheet | Near MCU |

### Core Module Power

| Parameter | Value |
|---|---|
| Input Voltage | +3V3 from carrier **or** USB VBUS (5V) |
| Module LDO | AP2112K-3.3 (from USB VBUS) |
| Power OR | Schottky diode OR: carrier 3.3V or LDO output |
| Module Consumption | ~350 mA max (MCU 300mA + BLE 10mA + LED 20mA) |
| Standalone Operation | Yes — powered from USB-C alone (for dev without carrier) |

Note: When on carrier, carrier supplies 3.3V via TPS63070. Module LDO is
bypassed (diode OR, carrier voltage wins). When standalone, USB VBUS powers
LDO → 3.3V for module only.

### Core Module PCB

| Parameter | Value |
|---|---|
| Dimensions | 40 x 25 mm |
| Layers | 4 (Signal / GND / Power / Signal)  |
| Edge Pads | 2x 30-pin castellated, 1.27mm pitch, both long edges |
| Solder Mask | Both sides, matte black |

## Carrier Board (Drone Application)

## IMU — ICM-42688-P

| Parameter | Value |
|---|---|
| Interface | SPI (up to 24 MHz) |
| Accel Range | +/- 16g (configurable) |
| Gyro Range | +/- 2000 deg/s (configurable) |
| Gyro Noise Density  | 2.8 mdps/rtHz |
| Accel Noise Density | 70 ug/rtHz |
| ODR (max) | 32 kHz (gyro), 32 kHz (accel) |
| On-chip FIFO | 2 KB |
| Package | LGA-14 (2.5 x 3.0 mm) |
| Supply | 1.71V - 3.6V |
| Current | 0.8 mA (gyro + accel, low-noise mode) |
| INT1 Pin | Data-ready interrupt to MCU EXTI |
| Decoupling | 100 nF on VDD, 1 uF on VDDIO |

### Placement Requirements

- Mount at PCB center of gravity
- Minimum 5 mm clearance from motor traces and power planes
- Local ground pour stitched with vias beneath IC
- No copper pour on layer directly beneath sensor (reduce stress)

## Barometer — BMP390

| Parameter | Value |
|---|---|
| Interface | I2C (up to 3.4 MHz) |
| I2C Address | 0x77 (SDO = HIGH) |
| Pressure Range | 300 - 1250 hPa |
| Relative Accuracy | +/- 0.03 hPa |
| Absolute Accuracy | +/- 0.5 hPa |
| Temperature Accuracy| +/- 0.5 C |
| ODR | Up to 200 Hz |
| Package | LGA-10 (2.0 x 2.0 mm) |
| Supply | 1.71V - 3.6V |
| Current | 0.7 mA (normal mode) |
| Decoupling | 100 nF on VDD |

### Placement Requirements

- Shield from direct airflow (place under foam or cover with tape)
- Keep away from heat sources (regulator, motor drivers)
- Vent hole in enclosure for pressure equalization

## Time-of-Flight — VL53L5CX

| Parameter | Value |
|---|---|
| Interface | I2C (up to 1 MHz) |
| I2C Address | 0x29 (default) |
| Range | 20 mm - 4000 mm |
| Zones | 4x4 or 8x8 multi-zone |
| Accuracy | +/- 5 mm (typical) |
| Ranging Rate | Up to 60 Hz |
| FoV | 63 deg (diagonal) |
| Package | Module 6.4 x 3.0 x 1.5 mm|
| Supply | 2.8V (from 3.3V via LDO) or 3.3V direct |
| Current | 18 mA (ranging active) |
| INT Pin | Ranging complete interrupt |
| Decoupling | 100 nF + 4.7 uF on AVDD  |

### Placement Requirements

- Mount on bottom side of PCB, facing down
- Clear optical path (no obstructions within 63 deg FoV cone)
- Cover glass must be clean and flush with PCB bottom surface

## Optical Flow — PMW3901

| Parameter | Value |
|---|---|
| Interface | SPI (up to 2 MHz) |
| Resolution | 30 x 30 pixel array |
| Frame Rate | Up to 121 fps |
| Optimal Height | 80 mm - 1 m |
| Motion Output | Delta-X, Delta-Y (int16)  |
| Package | Module ~15 x 20 mm |
| Supply | 1.8V - 3.6V |
| Current | 8 mA (tracking active) |
| Motion Pin | Motion detected interrupt  |
| Decoupling | 100 nF on VDD |

### Placement Requirements

- Mount on bottom side of PCB, facing down
- Lens must have clear view of ground
- Minimum 80 mm altitude for valid readings
- Co-locate with VL53L5CX for fused altitude + position

## BLE Module — MDBT42Q (nRF52832)

| Parameter | Value |
|---|---|
| Chipset | nRF52832 (Cortex-M4F) |
| BLE Version | 5.0 |
| Interface to STM32  | UART (up to 1 Mbps) |
| Antenna | On-module PCB antenna |
| TX Power | -20 to +4 dBm |
| Range | ~30 m (indoor) |
| Package | Module 16 x 10 x 2.2 mm |
| Supply | 1.7V - 3.6V |
| Current | 5 mA (TX), 5.4 mA (RX) |
| Additional Pins | Reset (from STM32 GPIO) |
| Decoupling | 100 nF + 10 uF on VDD |

### Functions

- BLE GATT server for telemetry streaming
- BLE DFU bootloader for OTA firmware updates (both nRF52 and STM32)
- Configuration interface (PID gains, flight parameters)
- Blackbox data download

### Placement Requirements

- Place at PCB edge with antenna facing outward
- Minimum 10 mm from IMU (reduce RF interference on analog sensors)
- Ground plane keepout under antenna area per module datasheet

## ELRS Receiver

| Parameter | Value |
|---|---|
| Module | BetaFPV ELRS Lite RX or HappyModel EP2 |
| Protocol | ExpressLRS 3.x |
| Frequency | 2.4 GHz |
| Packet Rate | 50 / 150 / 250 / 500 Hz |
| Latency | 2 - 5 ms |
| Interface | UART (CRSF protocol, 420000 baud) |
| Supply | 3.3V (or 5V, module dependent) |
| Current | ~40 mA |
| Weight | 0.5 - 0.9 g |
| Antenna | Ceramic chip or wire dipole|
| Size | ~10 x 10 mm (Lite RX) |

### Mounting

- Solder pads: 3V3, GND, TX, RX
- Antenna should be away from motors and carbon fiber frame
- Secure with double-sided tape or solder directly to FC pads

## Motor System

### Brushless Motors — 1404 4500KV

| Parameter | Value |
|---|---|
| Motor Class | 1404 |
| KV Rating | 4500 KV |
| Stator | 14 mm dia x 4 mm height |
| Max Thrust (3S, 3") | ~200 g per motor |
| Weight | ~8.5 g per motor |
| Shaft | 1.5 mm |
| Max Current | 5 A per motor |
| Connector | JST-PH 1.25 mm 3-pin or solder pads |
| Recommended | BetaFPV 1404 4500KV, FlyFishRC Flash 1404 4500KV |

For propeller specs, see [mechanical.md](mechanical.md).

### 4-in-1 ESC

| Parameter | Value |
|---|---|
| Type | 4-in-1 integrated ESC board |
| Firmware | **BlueJay** (required for bidirectional DSHOT300) |
| Protocol | Bidirectional DSHOT300 |
| Continuous Current  | 6 A per channel |
| Burst Current | 10 A per channel |
| MOSFET | Integrated on ESC board |
| Supply | **3S LiPo (9.0 - 12.6V)** |
| Size | ~20 x 20 mm mounting |
| Weight | ~2-3 g |
| Voltage Rating | >= 13V |

Alternative: discrete motor driver ICs (4x DRV8323 or equivalent, up to 60V)
integrated on main PCB if a custom ESC is preferred.

### Motor Layout

| Motor | Label | Position | Rotation | DSHOT Channel |
|---|---|---|---|---|
| M1 | FR | Front Right | CW | TIM1_CH1 |
| M2 | FL | Front Left  | CCW | TIM1_CH2 |
| M3 | BR | Back Right  | CCW | TIM1_CH3 |
| M4 | BL | Back Left | CW | TIM1_CH4 |

## Power Supply

### Battery — 3S LiPo

| Parameter | Value |
|---|---|
| Model | CNHL MiniStar 850mAh 3S 70C |
| Configuration | 3S (3 cells series) |
| Nominal Voltage | 11.1V |
| Full Charge Voltage  | 12.6V |
| Cutoff Voltage | 9.0V (3.0V per cell) |
| Capacity | 850 mAh |
| Discharge Rate | 70C continuous / 140C burst |
| Energy | 9.44 Wh |
| Main Connector | XT60 |
| Balance Connector | JST-XH 4-pin |
| Dimensions | 62 x 25 x 30 mm |
| Weight | ~80 g (with connector) |

### Balance Connector and Cell Monitoring

A JST-XH balance connector exposes individual cell voltages for both
**external balance charging** and **per-cell monitoring**.

| Parameter | Value |
|---|---|
| Connector | JST-XH 4-pin (3S standard) |
| Pinout | GND, CELL1+, CELL2+, CELL3+ (= +VBAT) |
| Position | Carrier board edge, near XT60 connector |
| Standard | Industry-standard LiPo balance port |
| Use 1 | Plug into external balance charger (primary charging method) |
| Use 2 | Per-cell ADC monitoring (always active) |

### Per-Cell Voltage Monitoring

Cell voltages are read via resistor dividers connected to STM32H743 ADC channels.
Only 2 ADC channels are needed: cell 1 directly, cell 2 cumulative (cell 1 + cell 2).
For 3S, cell 3 is computed as `pack_voltage - cell1 - cell2`.

| Cell | Source | ADC Channel | Divider | Max Input | ADC Voltage |
|---|---|---|---|---|---|
| CELL1 | JST-XH pin 2 (cell1+)| ADC1_INx (CELL1) | 10K / 10K (0.5)  | 4.4V | 2.2V |
| CELL2 | JST-XH pin 3 (cell1+cell2 sum)| ADC1_INy (CELL2) | 30K / 10K (0.25) | 8.8V | 2.2V |
| CELL3 | (computed for 3S) | -- | -- | -- | -- |
| Pack | +VBAT | ADC1_INz (VBAT)  | 30K / 10K (0.25) | 13.1V | 3.28V |

Conversion:
```
cell1_mv  = (adc1 * 3300 * 2) / 4095
cell12_mv = (adc2 * 3300 * 4) / 4095          // cumulative cell1 + cell2 voltage
cell2_mv  = cell12_mv - cell1_mv
cell3_mv  = pack_mv - cell12_mv               // 3S only
```

Cell1 and cell2 measured directly via ADC; cell3 computed from pack voltage.

### Cell Monitoring Features

The MCU uses cell voltages for:

| Feature | Description |
|---|---|
| Imbalance detection  | Refuse arm if max-min cell delta > 100 mV |
| Per-cell low voltage | Critical/cutoff thresholds applied per-cell, not just pack |
| Telemetry | Per-cell voltage reported via BLE and CRSF |
| Health logging | Blackbox logs per-cell voltage at 10 Hz |
| Battery age estimate | Track cycle count and voltage sag patterns |

For threshold values, see [safety.md](safety.md#low-battery-thresholds-per-cell-applies-to-1s--2s--3s).

### Battery Voltage Validation

The firmware validates 3S battery voltage at boot:

| Measured Voltage  | State | Action |
|---|---|---|
| 9.0V - 13.1V | 3S OK | Normal operation |
| < 9.0V | No battery / depleted | USB-only power; refuse arm |

Validation runs once at boot before calibration. All battery thresholds
are expressed as per-cell voltages (3.0V cutoff, 3.3V critical, 3.5V warning)
and applied to the 3-cell pack.

### Power Domains

| Domain  | Voltage | Source | Loads |
|---|---|---|---|
| +VBAT | 9.0 - 12.6V | Battery direct (via XT60)| ESC / Motors, VTX power |
| +3V3 | 3.3V | TPS63070 output | MCU, IMU, Baro, ToF, OF, BLE, ELRS, Flash, LED, Buzzer |
| +VUSB | 5.0V | USB-C VBUS | Core module LDO (standalone power), USB peripheral |
| GND | 0V | Common ground | All |

Note: No onboard battery charging. Use an external balance charger via the
JST-XH balance connector for 3S batteries.

### Buck-Boost Regulator — TPS63070

| Parameter | Value |
|---|---|
| Topology | Buck-boost (step up/down) |
| Input Range | **2.0V - 16V** |
| Output | 3.3V (set by resistor divider) |
| Max Output Current | 2 A |
| Efficiency | ~93% (typical, varies with Vin) |
| Switching Frequency  | 2.4 MHz |
| Package | VQFN-14 (3.5 x 3.5 mm) |
| Inductor | 1.5 uH (shielded, low DCR, 3A rated) |
| Input Capacitor | 10 uF x2 MLCC (X5R/X7R, **25V rated**) |
| Output Capacitor | 22 uF x2 MLCC (X5R/X7R) |
| Feedback Divider | R_TOP: 1M, R_BOT: 470K (3.3V out) |

Note: TPS63070 operates in buck mode for 3S (input 9.0-12.6V, always > 3.3V output).

### Battery Charging — External Only

No onboard battery charger. Charging is performed via an external LiPo
balance charger plugged into the JST-XH balance connector. This is the
standard practice for 2S/3S drones and avoids the weight and complexity of
onboard multi-cell charging.

USB-C is still used for:
- Programming (DFU and SWD via separate header)
- Debug serial (USB CDC)
- Powering the core module standalone (without battery)

### USB-C Connector

| Parameter | Value |
|---|---|
| Connector | USB Type-C 2.0 receptacle (mid-mount or SMD) |
| ESD Protection | USBLC6-2SC6 (SOT-23-6) |
| CC Resistors | 2x 5.1K to GND (UFP, device mode) |
| Functions | USB DFU, USB CDC serial, standalone power |

### Power Switch — High-Side P-FET

| Parameter | Value |
|---|---|
| Switch Type | P-channel MOSFET (e.g., **DMP3010LK3**) |
| Vds Rating | **-30V** (sufficient for 3S: 12.6V) |
| Control | SW2 slide switch (gate control) |
| Rds(on) | < 35 mohm |
| Features | Clean power cutoff, no contact resistance issues |
| Status LED | Green LED downstream of switch (power indicator) |

### Reverse Polarity Protection

| Parameter | Value |
|---|---|
| Method | P-channel MOSFET body diode |
| MOSFET | Same DMP3010LK3 (**-30V rated**) |
| Voltage Drop | < 30 mV at load (Rds(on) path) |

### Overcurrent Protection

| Parameter | Value |
|---|---|
| Device | Resettable PTC fuse |
| Rating | **5A hold / 10A trip** |
| Package | 1210 SMD |
| Location | Between battery connector and power switch |

Note: PTC rated for worst-case 3S full-throttle current. 4 motors can draw
~12 A peak; the 10 A trip protects against short circuits while allowing
brief burst peaks (PTC has thermal time constant).

### Decoupling — Core Module

| Capacitor | Value | Package | Purpose |
|---|---|---|---|
| C_VDD (x8) | 100 nF  | 0402 | MCU VDD bypass (each VDD pin)  |
| C_VDDA | 1 uF + 100 nF | 0402 | MCU analog supply |
| C_VCAP (x2) | 2.2 uF  | 0402 | H743 internal LDO (VCAP pins) |
| C_LDO_IN | 10 uF | 0603 | AP2112K input |
| C_LDO_OUT | 10 uF | 0603 | AP2112K output |
| C_BLE | 100 nF + 10 uF | 0402/0603 | nRF52 module VDD |
| C_USB | 100 nF  | 0402 | USB VBUS decoupling |

### Decoupling — Carrier Board

| Capacitor | Value | Package | Purpose |
|---|---|---|---|
| C_IN_BUCK (x2)  | 10 uF | 0805 25V | Buck-boost input |
| C_OUT_BUCK (x2) | 22 uF | 0805 | Buck-boost output |
| C_IMU | 100 nF + 1 uF | 0402 | ICM-42688 VDD + VDDIO |
| C_BARO | 100 nF  | 0402 | BMP390 VDD |
| C_TOF | 100 nF + 4.7 uF | 0402/0603 | VL53L5CX AVDD |

## Data Storage

STM32H743 has 2 MB dual-bank internal flash. Bank 2 (1 MB) is used for
blackbox logging, eliminating the need for external SPI flash.

| Parameter | Value |
|---|---|
| Blackbox Storage | 1 MB (internal flash bank 2)|
| Page Size | 256 bytes (flash word = 32 bytes) |
| Sector Size | 128 KB |
| Endurance | 10K erase cycles per sector |
| Write Speed | ~3.5 MB/s (via internal bus)|

Note: If more blackbox capacity is needed, an external W25Q128 SPI flash
(16 MB) can be added on the carrier board via SPI4. The core module exposes
SPI4 on the castellated pads for this purpose.

## Oscillators (on Core Module)

| Crystal | Frequency | Package | Load Capacitors | Purpose |
|---|---|---|---|---|
| Y1 | 25 MHz (HSE) | SMD 2520-4Pin | 2x 10 pF (0402) | PLL → 480 MHz |
| Y2 | 32.768 kHz (LSE)| SMD 3215-2Pin | 2x 6.8 pF (0402) | USB SOF, RTC |

Note: H743 requires HSE for USB HS PHY. 25 MHz chosen for clean PLL
multiplication to 480 MHz system clock and 48 MHz USB clock.

## PCB — Core Module

| Parameter | Value |
|---|---|
| Dimensions | 40 x 25 mm |
| Layers | 4 (Signal / GND / Power / Signal)  |
| Dielectric | FR4, 1.0 mm total |
| Copper Thickness  | 35 um (1 oz) outer, 17.5 um (0.5 oz) inner |
| Min Track Width | 0.15 mm (6 mil) |
| Min Clearance | 0.15 mm (6 mil) |
| Edge Pads | Castellated half-holes, 1.27 mm pitch |
| Solder Mask | Both sides, matte black |

### Core Module Design Rules

- H743 LQFP-100 at board center; decoupling caps within 2 mm of VDD pins
- VCAP caps immediately adjacent to VCAP1/VCAP2 pins (critical for internal LDO)
- BLE module antenna at board edge with ground keepout
- USB-C at short edge for easy access
- SWD and buttons at opposite short edge
- 25 MHz HSE crystal within 10 mm of OSC_IN/OSC_OUT
- Continuous GND plane on L2

## PCB — Carrier Board

| Parameter | Value |
|---|---|
| Dimensions | 50 x 50 mm (max) |
| Layers | 4 (Signal / GND / Power / Signal)  |
| Dielectric | FR4, 1.6 mm total |
| Copper Thickness  | 35 um (1 oz) outer, 17.5 um (0.5 oz) inner |
| Min Track Width | 0.15 mm (6 mil) |
| Mounting Holes | 4x M2 at 20 x 20 mm pattern (ESC stack) |
| Module Socket | 2x 30-pin SMD socket pads, 1.27mm pitch |

### Carrier Board Track Width Classes

| Width | Typical Use |
|---|---|
| 0.15 mm | Fine signal (SPI, I2C, GPIO) |
| 0.25 mm | Standard signal |
| 0.50 mm | 3.3V rail (up to 1 A) |
| 1.50 mm | Per-motor power trace (up to 5 A) |
| **Copper pour** | **Battery main +VBAT / GND (>5 A)**  |

Battery rail (+VBAT, GND) must use **copper pours on L1 + L4** stitched with
power vias every 2-3mm. Do not use single traces for battery or ESC input —
3S at full throttle draws up to 20 A peak (4 × 5 A).

### Carrier Sensor Power Switch

| Parameter | Value |
|---|---|
| Device | TPS22918 load switch (SOT-23-5) |
| Control | STM32 GPIO (active high) |
| Load | IMU, Baro, ToF, OF (all 3.3V sensors) |
| Max Current | 500 mA (TPS22918 rated 2A) |
| Purpose | H743 boots first, then enables sensor power after 100 ms |

This fixes Gen 1 HW-08 (IMU/BT power sequence) definitively. Sensors
don't see power spikes during MCU boot or regulator startup.

### Carrier Board Design Rules

- Core module socket at board center-top
- IMU (ICM-42688-P) at board center (near CG)
- Minimum 10 mm between module BLE antenna and IMU
- Battery/ESC power: copper pour on L1 + L4, **not single traces**
- TPS63070 + LC filter near XT60 connector
- Sensor power via TPS22918 load switch (GPIO-controlled)
- Barometer covered with foam; isolated from motor airflow
- GPS + camera connectors at board edge (JST-GH)
- Companion computer header at board edge
- ToF + Optical Flow on bottom side, facing down

### Carrier GPS Connector (Removable Module)

| Parameter | Value |
|---|---|
| Connector | JST-GH 4-pin, 1.25 mm pitch |
| Signals | 3V3, GND, TX (UART4), RX (UART4)  |
| Baud Rate | 38400 (default, configurable) |
| Protocol | NMEA / UBX (auto-detect) |
| Recommended Module| HGLRC M100 Mini (2.8g, u-blox M10, 15x15mm) |
| Alternative | Flywoo GM10 Mini V3 (3.5g, M10 + compass, 20x20mm) |
| Mounting | Velcro or 3D-printed pylon on top of frame |

When GPS is not installed, the connector adds <0.3g. The firmware auto-detects
GPS presence (NMEA sentence received within 2s of boot). If no GPS is detected,
GPS-dependent features (position hold outdoor, RTH) are disabled gracefully.

### Carrier Camera / VTX Connector (Removable Module)

| Parameter | Value |
|---|---|
| Power Pads | +VBAT (direct battery, for VTX), GND |
| Signal Connector  | JST-GH 3-pin: 3V3, TX (UART3), RX (UART3) |
| UART Purpose | VTX control (SmartAudio / MSP DisplayPort) |
| Recommended | HDZero Whoop Lite VTX (4.5g) + Nano90 camera (2.5g) = 7g total |
| Alternative | Analog AIO (Caddx Ant Lite, ~3g total) |
| Alternative | ESP32-CAM (WiFi streaming to phone, ~5g) |
| Mounting | VTX on frame top plate; camera on front tilt mount |

The VTX draws power directly from +VBAT (9-12.6V, within HDZero/analog VTX input range).
The UART provides SmartAudio control (change channel, power) or MSP DisplayPort
for OSD overlay. When no VTX is installed, the pads add <0.2g.

### Carrier Companion Computer Header

| Parameter | Value |
|---|---|
| Connector | 1x4 pin header, 2.54 mm pitch |
| Signals | 3V3, GND, TX (UART7), RX (UART7)  |
| Baud Rate | Configurable (default 921600) |
| Purpose | Future RPi Zero / ESP32 companion  |
| Protocol | MAVLink or custom binary |

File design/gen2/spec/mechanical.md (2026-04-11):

# Mechanical Specification (Gen 2)

## Design Constraints

| Parameter | Value |
|---|---|
| Max Body Size | 200 mm (W) x 200 mm (L), excluding propellers |
| Target AUW | 141 g |
| Configuration | Quadrotor (X-config) |
| Use Environment | Indoor / calm outdoor |

## Frame

| Parameter | Value |
|---|---|
| Configuration | Quadrotor X-frame |
| Material | 3D-printed (TPU/PLA) or carbon fiber plate |
| Motor-to-motor | 130 - 150 mm (diagonal) |
| Arm Width | 8 - 10 mm |
| Arm Thickness | 3 - 4 mm |
| Center Stack | 20 x 20 mm M2 mounting pattern (standard FC/ESC stack) |
| Prop Guard | Optional snap-on TPU guards |

### Frame Layout (Top View)

```
             200 mm max (body)
        +-------------------------+
        |                         |
        |    FL            FR     |     Prop circle (76 mm / 3")
        |     \   ______   /     |     extends beyond body
        |      \ | PCB  | /      |
        |       \| 50x50|/       |
        |        |______|        |
        |       /        \       |
        |      /          \      |
        |    BL            BR    |
        |                         |
        +-------------------------+
```

### Frame Options

| Option | Material | Weight | Pros | Cons |
|---|---|---|---|---|
| A | 3D-printed PLA | ~8 g | Easy to iterate, cheap | Brittle, heavier |
| B | 3D-printed TPU | ~6 g | Flexible, crash resistant | Less rigid, slight vibration |
| C | CF plate (1 mm)| ~5 g | Lightest, stiffest | Harder to manufacture, RF blocking |
| D | PCB-integrated | 0 g | No separate frame needed | PCB must be large enough for arms |

Recommended: **Option B (TPU)** for development, **Option C (CF)** for final version.

If PCB is designed as a full unibody (Option D), arms extend from PCB edges
with motor pads at tips. This eliminates frame weight entirely but limits
PCB shape to the airframe outline.

## Motor Layout

```
        Front
    FL -------- FR
    |            |
    |    PCB     |
    |   (stack)  |
    BL -------- BR
         Back
```

For motor labels (M1-M4), rotation directions, and DSHOT channel assignments,
see [hardware.md](hardware.md#motor-layout).

## Propellers

| Parameter | Value |
|---|---|
| Size | 76 mm (3 inch) |
| Blade Count | 2-blade or 3-blade |
| Material | Polycarbonate |
| Mounting | Press-fit on 1 mm shaft |
| Weight | ~1 g per prop (2-blade) |
| Recommended | HQProp 3x1.5x3 or Gemfan 3018 |

Note: 2.5" props (65 mm) are an alternative for tighter body constraint.
Trade-off: less thrust but fits more easily within 200 mm body limit.

## Motor Specifications

For motor electrical specs (KV, current, thrust), see
[hardware.md](hardware.md#brushless-motors--1404-4500kv).

| Motor Class | Shaft | Weight/Motor |
|---|---|---|
| 1404 | 1.5 mm  | ~8.5 g |

## Battery

For battery electrical specs, see [hardware.md](hardware.md#battery--3s-lipo).

| Model | Capacity | Dimensions (mm) | Weight |
|---|---|---|---|
| CNHL MiniStar 3S | 850 mAh | 62 x 25 x 30 | ~80 g  |

### Battery Mounting

Battery mounts underneath the PCB (center of gravity aligned with thrust center).
Secured by:
- Silicone rubber band (lightweight, quick-swap)
- Or 3D-printed battery tray integrated into frame
- XT60 connector accessible from rear for easy swap
- Battery bay must accommodate 62 x 25 x 30 mm

## Weight Budget

### Common Components

| Component | Count | Unit Weight (g) | Total (g) |
|---|---|---|---|
| Core + Carrier PCBs | 2 | - | 12 |
| 4-in-1 ESC (20x20 stack)| 1 | 2.5 | 2.5 |
| ELRS Lite RX | 1 | 0.5 | 0.5 |
| Frame (TPU 3D-print) | 1 | 6 | 6 |
| Wiring / solder / misc  | -- | -- | 2 |
| **Common subtotal** | | | **23** |

### Drone-Specific Components

| Component | Weight |
|---|---|
| 1404 motors (x4) | 34 g |
| 3" propellers (x4) | 4 g |
| CNHL 3S 850mAh battery  | 80 g |
| **Subtotal** | **118 g** |

### Total AUW

| Common | Drone | **Total AUW** | T/W Ratio | T/W with 100g payload |
|---|---|---|---|---|
| 23 g | 118 g | **141 g** | 5.7 : 1 | 3.3 : 1 |

### Weight Optimization Paths

| Change | Savings |
|---|---|
| CF frame (replace TPU) | ~1-2 g  |
| Discrete ESC on carrier PCB | ~1.5 g  |
| Lighter battery (450 mAh) | ~40 g (AUW ~101g, T/W 7.9:1) |

## Center of Gravity

| Requirement | Specification |
|---|---|
| CG horizontal | Within 5 mm of geometric center|
| CG vertical | Below motor plane (battery underneath helps) |
| IMU placement | At CG or within 3 mm |

Battery position is the primary CG adjustment tool. Slide battery forward/back
to balance.

## Vibration Management

| Source | Mitigation |
|---|---|
| Motor vibration | Soft-mount motors (silicone O-rings on motor screws) |
| Prop imbalance | Use factory-balanced props; replace damaged props |
| IMU vibration isolation  | Gyro notch filter in firmware (ICM-42688 provides); optional foam pad under IMU if on breakout board |
| Frame resonance | TPU frame absorbs vibration; CF frame may need motor soft-mounting |

## Connectors

### Core Module
| Ref  | Type | Pitch | Purpose |
|---|---|---|---|
| J1 | USB-C receptacle | -- | Programming, USB CDC, standalone power |
| J2 | PinHeader 1x04 vert | 1.27 mm | SWD debug |
| EDGE | Castellated pads x120  | 1.27 mm | Carrier interface (2x 30-pin, both edges) |

### Carrier Board
| Ref  | Type | Pitch | Purpose |
|---|---|---|---|
| J3 | XT60 connector | -- | Battery main power (3S) |
| J4 | JST-XH 1x04 | 2.5 mm  | Battery balance port (3S)  |
| J7 | JST-GH 1x04 | 1.25 mm | GPS module (removable) |
| J8 | JST-GH 1x03 + VBAT pads| 1.25 mm | Camera / VTX (removable) |
| J9 | Push-push MicroSD slot  | -- | Blackbox logging (FAT32) |
| J5 | PinHeader 1x04 vert | 2.54 mm | Companion computer UART |
| J6 | Module socket pads | 1.27 mm | Core module mounting (2x 30-pin) |
| M1-4 | Motor pads (solder) | -- | Brushless motors (3 pads each) |
| ELRS | Solder pads (4-pin) | 1.27 mm | ELRS receiver |

Note: JST-XH balance port serves both per-cell ADC monitoring (always active)
and external balance charging (when plugged into LiPo charger).

## Assembly Stack-Up

```
Side view (not to scale):

    Propellers
    -----------      <- Props press-fit on motor shafts
    |  Motors  |     <- Motors mounted on frame arms
    ===========      <- Frame (TPU/CF arms)
    |   PCB    |     <- Main flight controller PCB
    |  (ESC)   |     <- 4-in-1 ESC (20x20 stack under PCB, or integrated)
    -----------
    | Battery  |     <- Battery strapped underneath
    -----------
    [ToF] [OF]       <- Bottom-facing sensors (VL53L5CX + PMW3901)
```

### Stack Height Budget

| Layer | Height (mm) |
|---|---|
| Propeller clearance  | 3 |
| Motor height | 6 |
| Frame arm | 4 |
| PCB + ESC stack | 8 |
| Battery | 7 |
| Bottom sensors | 3 |
| **Total** | **~31 mm**  |

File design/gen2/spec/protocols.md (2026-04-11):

# Protocol Specification (Gen 2)

Note: Bus assignments reference STM32H743VIH6 peripherals. SPI/I2C/UART
signals are routed from the core module to the carrier board via castellated
pads — see [hardware.md](hardware.md#pin-allocation-on-connector).

## SPI1 — IMU Communication (ICM-42688-P)

| Parameter | Value |
|---|---|
| Bus | SPI1 (carrier, via core module passthrough) |
| Device | ICM-42688-P |
| Mode | SPI Mode 3 (CPOL=1, CPHA=1) |
| Clock | 8 MHz (normal), 24 MHz (burst read) |
| CS Pin | CS_IMU (active low) |
| Signals | SPI1_SCK, SPI1_MISO, SPI1_MOSI, CS_IMU |
| INT1 | Data-ready interrupt (active high, push-pull) |

### ICM-42688-P Register Map (Key Registers)

Register Bank 0 (default):

| Register | Address | R/W | Description |
|---|---|-----|---|
| DEVICE_CONFIG | 0x11 | R/W | SPI mode, soft reset |
| INT_CONFIG | 0x14 | R/W | INT1/INT2 configuration |
| FIFO_CONFIG | 0x16 | R/W | FIFO mode selection |
| TEMP_DATA1 | 0x1D | R | Temperature data high byte |
| TEMP_DATA0 | 0x1E | R | Temperature data low byte  |
| ACCEL_DATA_X1 | 0x1F | R | Accel X high byte |
| ACCEL_DATA_X0 | 0x20 | R | Accel X low byte |
| ACCEL_DATA_Y1 | 0x21 | R | Accel Y high byte |
| ACCEL_DATA_Y0 | 0x22 | R | Accel Y low byte |
| ACCEL_DATA_Z1 | 0x23 | R | Accel Z high byte |
| ACCEL_DATA_Z0 | 0x24 | R | Accel Z low byte |
| GYRO_DATA_X1 | 0x25 | R | Gyro X high byte |
| GYRO_DATA_X0 | 0x26 | R | Gyro X low byte |
| GYRO_DATA_Y1 | 0x27 | R | Gyro Y high byte |
| GYRO_DATA_Y0 | 0x28 | R | Gyro Y low byte |
| GYRO_DATA_Z1 | 0x29 | R | Gyro Z high byte |
| GYRO_DATA_Z0 | 0x2A | R | Gyro Z low byte |
| INT_STATUS | 0x2D | R | Interrupt status (clear on read) |
| PWR_MGMT0 | 0x4E | R/W | Accel/gyro power mode |
| GYRO_CONFIG0 | 0x4F | R/W | Gyro FS and ODR |
| ACCEL_CONFIG0 | 0x50 | R/W | Accel FS and ODR |
| GYRO_CONFIG1 | 0x51 | R/W | Gyro filter bandwidth |
| ACCEL_CONFIG1 | 0x53 | R/W | Accel filter bandwidth |
| WHO_AM_I | 0x75 | R | Device ID (expected: 0x47) |
| BANK_SEL | 0x76 | R/W | Register bank selection |

### SPI Transaction Format

Read: CS low → [reg_addr | 0x80] → [dummy_byte(s)] → read data → CS high
Write: CS low → [reg_addr & 0x7F] → [data] → CS high

Burst read of 12 bytes (accel + gyro):
CS low → [0x1F | 0x80] → read 12 bytes (ACCEL_X_H through GYRO_Z_L) → CS high

### Recommended Initialization

```
1. Soft reset: DEVICE_CONFIG = 0x01, wait 1 ms
2. Verify WHO_AM_I = 0x47
3. Set gyro: GYRO_CONFIG0 = 0x06 (2000 dps, 1 kHz ODR)
4. Set accel: ACCEL_CONFIG0 = 0x06 (16g, 1 kHz ODR)
5. Set filter: GYRO_CONFIG1 BW = ODR/4 (anti-alias)
6. Enable INT1 data-ready: INT_CONFIG = 0x02
7. Power on: PWR_MGMT0 = 0x0F (gyro LN + accel LN)
8. Wait 30 ms for gyro startup
```

## SPI2 — Shared Bus (Flash + Optical Flow)

| Parameter | Value |
|---|---|
| Bus | SPI2 |
| Devices | W25Q128 (flash), PMW3901 (OF) |
| Mode | SPI Mode 0 (CPOL=0, CPHA=0) for flash; Mode 3 for PMW3901 |
| Clock | 8 MHz (flash), 2 MHz (PMW3901)|
| CS Pins | CS_FLASH, CS_OF (active low)  |
| Signals | SPI2_SCK, SPI2_MISO, SPI2_MOSI |

Note: SPI mode differs between devices. Reconfigure SPI mode before each
device transaction, or use separate SPI peripherals if timing is critical.
Alternative: use SPI3 for PMW3901 if available pins permit.

### W25Q128 Flash Commands

| Command | Opcode | Description |
|---|---|---|
| Read Data | 0x03 | Read bytes from address |
| Fast Read | 0x0B | Read with dummy byte |
| Page Program | 0x02 | Write up to 256 bytes |
| Sector Erase | 0x20 | Erase 4 KB sector |
| Block Erase 32K  | 0x52 | Erase 32 KB block |
| Block Erase 64K  | 0xD8 | Erase 64 KB block |
| Chip Erase | 0xC7 | Erase entire chip |
| Write Enable | 0x06 | Must precede any write/erase  |
| Read Status Reg  | 0x05 | Check BUSY bit |
| Read JEDEC ID | 0x9F | Manufacturer + device ID |

### PMW3901 Optical Flow Registers

| Register | Address | Description |
|---|---|---|
| Product_ID | 0x00 | Expected: 0x49 |
| Motion | 0x02 | Motion detected flag |
| Delta_X_L | 0x03 | X motion low byte |
| Delta_X_H | 0x04 | X motion high byte |
| Delta_Y_L | 0x05 | Y motion low byte |
| Delta_Y_H | 0x06 | Y motion high byte |
| SQUAL | 0x07 | Surface quality (0-169) |

Read: [reg_addr & 0x7F] → wait 50 us → read byte
Write: [reg_addr | 0x80] → data byte → wait 50 us

## I2C1 — Shared Bus (Barometer + ToF)

| Parameter | Value |
|---|---|
| Bus | I2C1 (carrier, via core module passthrough) |
| Devices | BMP390 (0x77), VL53L5CX (0x29)|
| Speed | 400 kHz (Fast Mode) |
| Pull-ups | 4.7K to 3.3V (R1, R2) |
| Signals | I2C1_SDA, I2C1_SCL |

### BMP390 Register Map (Key Registers)

| Register | Address | Description |
|---|---|---|
| CHIP_ID | 0x00 | Device ID (expected: 0x60) |
| ERR_REG | 0x02 | Error status |
| STATUS | 0x03 | Sensor status |
| DATA_0 | 0x04 | Pressure XLSB |
| DATA_1 | 0x05 | Pressure LSB |
| DATA_2 | 0x06 | Pressure MSB |
| DATA_3 | 0x07 | Temperature XLSB |
| DATA_4 | 0x08 | Temperature LSB |
| DATA_5 | 0x09 | Temperature MSB |
| PWR_CTRL | 0x1B | Pressure/temp enable, mode |
| OSR | 0x1C | Oversampling settings |
| ODR | 0x1D | Output data rate |
| CONFIG | 0x1F | IIR filter coefficient |
| NVM_PAR (21 bytes)| 0x31-0x45 | Calibration coefficients  |

### VL53L5CX Interface

The VL53L5CX uses a proprietary firmware upload + register interface over I2C.

| Operation | Description |
|---|---|
| FW Upload | ~86 KB firmware loaded at boot |
| Start Ranging | Configure resolution (4x4/8x8), frequency, integration time |
| Get Data | Read ranging results (distance per zone + status) |
| INT Pin | Asserted when new data ready |

Note: Use ST's VL53L5CX Ultra Lite Driver (ULD) API for all interactions.
The driver handles firmware upload, configuration, and data parsing.

### I2C Bus Recovery

If SDA is stuck low (bus hang), execute recovery sequence:
1. Configure SCL as GPIO output, SDA as GPIO input
2. Clock SCL 9 times (toggle high/low)
3. Check if SDA is released (high)
4. Generate STOP condition (SDA low-to-high while SCL high)
5. Reconfigure pins as I2C alternate function

## USART1 — ELRS Receiver (CRSF Protocol)

| Parameter | Value |
|---|---|
| UART | USART1 (carrier, via core module passthrough) |
| Baud Rate | 420000 |
| Data Bits | 8 |
| Stop Bits | 1 |
| Parity | None |
| Flow Control | None |
| Direction | Half-duplex (TX for telemetry, RX for RC data) or full-duplex |
| Signals | USART1_TX, USART1_RX |

### CRSF Frame Format

```
[SYNC] [LEN] [TYPE] [PAYLOAD...] [CRC]
 0xC8   1B    1B     N bytes      1B
```

| Field | Size  | Description |
|---|---|---|
| SYNC | 1 | Sync byte: 0xC8 (from TX) or 0xEE (from FC) |
| LEN | 1 | Length of TYPE + PAYLOAD + CRC |
| TYPE | 1 | Frame type |
| PAYLOAD | N | Type-dependent payload |
| CRC | 1 | CRC8 (DVB-S2 polynomial 0xD5) |

### CRSF Frame Types (Used)

| Type | Value | Direction | Description |
|---|---|---|---|
| RC Channels Packed | 0x16 | RX → FC | 16 channels, 11-bit each |
| Link Statistics | 0x14 | RX → FC | RSSI, LQ, SNR, TX power  |
| Battery Sensor | 0x08 | FC → TX | Voltage, current, mAh, % |
| Attitude | 0x1E | FC → TX | Pitch, roll, yaw |
| Flight Mode | 0x21 | FC → TX | Mode name string |
| GPS | 0x02 | FC → TX | Lat, lon, alt, speed |

### RC Channels Packed (0x16)

16 channels packed as 11-bit values (176 bits = 22 bytes payload).
Channel value range: 172 - 1811 (CRSF standard).
Center: 992. Endpoints: 172 (min), 1811 (max).

```
Byte layout (little-endian bitstream):
  ch0  = bits[0:10]
  ch1  = bits[11:21]
  ch2  = bits[22:32]
  ...
  ch15 = bits[165:175]
```

### Channel Mapping

For channel-to-function assignment and EdgeTX mixer setup,
see [remote_controller.md](remote_controller.md#channel-assignment-edgetx-mixer).

For channel-to-drone_cmd_t mapping,
see [behavioral.md](behavioral.md#crsf-backend-mapping).

### CRSF CRC8 Calculation

Polynomial: 0xD5 (DVB-S2)
Initial value: 0x00
Input: TYPE + PAYLOAD bytes (excludes SYNC and LEN)

```c
uint8_t crsf_crc8(const uint8_t *data, uint8_t len) {
    uint8_t crc = 0;
    for (uint8_t i = 0; i < len; i++) {
        crc ^= data[i];
        for (uint8_t j = 0; j < 8; j++) {
            crc = (crc & 0x80) ? (crc << 1) ^ 0xD5 : (crc << 1);
        }
    }
    return crc;
}
```

### CRSF Failsafe

For failsafe triggers and system-level actions,
see [safety.md](safety.md#failsafe-conditions).

## USART2 — BLE Module (nRF52832)

| Parameter | Value |
|---|---|
| UART | USART2 (on core module, directly connected to nRF52) |
| Baud Rate | 115200 |
| Data Bits | 8 |
| Stop Bits | 1 |
| Parity | None |
| Flow Control | None |
| Signals | USART2_TX, USART2_RX |

### BLE Transport Modes

The BLE link supports two transport modes over the same NUS (Nordic UART Service):

| Mode | Purpose | Protocol |
|---|---|---|
| **Shell**  | Runtime command line (debug, config) | Zephyr shell (ASCII text, interactive) |
| **Binary** | Structured telemetry and commands | Length-delimited binary (below) |

The nRF52 module runs NUS (UUID 6E400001-B5A3-F393-E0A9-E50E24DCCA9E).
Any BLE terminal app (nRF Connect, BLESerial nRF, Wible) connects to NUS
and gets interactive shell access. Structured telemetry uses the binary
protocol for programmatic access (phone app, GATT characteristics).

### BLE Binary Protocol

Messages between STM32 and nRF52 use a simple length-delimited binary protocol:

```
[START] [LEN] [CMD] [PAYLOAD...] [CSUM]
 0xAA    1B    1B    N bytes      1B
```

| Field | Size  | Description |
|---|---|---|
| START | 1 | Start byte: 0xAA |
| LEN | 1 | Length of CMD + PAYLOAD (1-252) |
| CMD | 1 | Command / message type |
| PAYLOAD | 0-251 | Command-dependent payload |
| CSUM | 1 | XOR checksum of LEN + CMD + PAYLOAD |

### BLE Command Types

| CMD  | Name | Direction | Payload |
|---|---|---|---|
| 0x01 | TELEM_BATTERY | STM32 → nRF | voltage_mv (uint16 LE) |
| 0x02 | TELEM_IMU | STM32 → nRF | ax,ay,az,gx,gy,gz (6x int16 LE) |
| 0x03 | TELEM_MODE | STM32 → nRF | mode (uint8) |
| 0x04 | TELEM_ERROR | STM32 → nRF | error_code (uint8) |
| 0x05 | TELEM_LOWBATT | STM32 → nRF | level (uint8: 1=warn, 2=crit) |
| 0x06 | TELEM_CALIB | STM32 → nRF | result (uint8: 1=ok, 0=fail) |
| 0x07 | TELEM_ALTITUDE | STM32 → nRF | alt_cm (int32 LE) |
| 0x08 | TELEM_LINK_STATS  | STM32 → nRF | rssi (int8), lq (uint8) |
| 0x10 | CMD_SET_PID | nRF → STM32 | axis(u8), Kp(f32), Ki(f32), Kd(f32) |
| 0x11 | CMD_BLACKBOX_DL | nRF → STM32 | offset(u32), length(u32)  |
| 0x12 | CMD_BLACKBOX_ERASE| nRF → STM32 | (none) |
| 0x13 | CMD_FIND_ME | nRF → STM32 | enable (uint8: 1=on, 0=off) |
| 0x20 | BLACKBOX_DATA | STM32 → nRF | raw flash bytes (up to 240B) |
| 0xF0 | DFU_START | nRF → STM32 | image_size (uint32 LE) |
| 0xF1 | DFU_DATA | nRF → STM32 | offset(u32), data(up to 240B) |
| 0xF2 | DFU_COMPLETE | nRF → STM32 | crc32 (uint32 LE) |
| 0xFE | ACK | Both | cmd_acked (uint8) |
| 0xFF | NACK | Both | cmd_nacked (uint8), error(uint8) |

## USB — DFU and CDC Serial

| Parameter | Value |
|---|---|
| Interface | USB 2.0 Full Speed (12 Mbps)  |
| Classes | DFU (Device Firmware Upgrade) + CDC ACM (virtual COM port) |
| VID/PID | TBD (use ST default for DFU)  |
| CDC Baud | Virtual (any baud, transparent to USB) |

### USB Boot Mode

- Normal boot: USB enumerates as CDC ACM (serial terminal for debug/config/blackbox)
- DFU boot (SW1 held > 3 s at power-on): USB enumerates as DFU class
- DFU uses STM32H7 built-in ROM bootloader or custom DFU bootloader

## DSHOT — Motor Control Protocol (Bidirectional DSHOT300)

Gen 2 uses **bidirectional DSHOT300** (also called BDShot300, DSHOT300_BIDIR).
This is a half-duplex protocol where the FC sends throttle commands and the
ESC responds with eRPM telemetry on the same signal wire.

| Parameter | Value |
|---|---|
| Protocol | DSHOT300 bidirectional |
| Bit Rate | 300 kbit/s (TX), ~375 kbit/s (RX, GCR) |
| Frame Size (TX) | 16 bits |
| Frame Size (RX) | 21 GCR nibbles → 16-bit eRPM |
| Bit Period | 3.33 us |
| Inverted | Yes (idle high, active low — bidirectional spec) |
| Timer | TIM1 (CH1-CH4) via DMA |
| Pin Mode | Open-drain with pull-up (allows both directions) |
| Update Rate | Matches rate PID loop (4 kHz) — see [performance.md](performance.md) |
| ESC Firmware | **BlueJay** (recommended) or BLHeli_S with bidirectional patch |

### DSHOT TX Frame Format (FC → ESC)

```
[THROTTLE (11 bit)] [TELEMETRY REQUEST (1 bit)] [CRC (4 bit)]
  bits 15-5              bit 4                     bits 3-0
```

| Field | Bits  | Description |
|---|---|---|
| Throttle  | 15-5  | 0 = disarmed, 48-2047 = throttle range |
| Telemetry | 4 | Always 0 in bidirectional mode (eRPM is automatic) |
| CRC | 3-0 | XOR checksum (inverted in bidir mode) |

### DSHOT RX Frame Format (ESC → FC)

After each TX frame, the ESC responds with a 16-bit value encoded as 21 GCR
(Gaussian Code Representation) nibbles. The 16-bit value contains:

| Field | Bits  | Description |
|---|---|---|
| eRPM | 15-4  | 12-bit eRPM exponent + mantissa |
| CRC | 3-0 | 4-bit CRC over eRPM bits |

eRPM encoding: `eRPM = mantissa << exponent` (exponent in upper 3 bits of the 12 bits)

Mechanical RPM: `rpm = (eRPM * 60) / pole_pairs`

For 1404 motors (typically 7 pole pairs / 14 magnets): `rpm = eRPM * 60 / 7`

### Cycle Timing

```
Time → (per motor channel, ~100 us total)

  [TX DSHOT frame: 53.3 us] [Gap: ~30 us] [RX GCR response: ~25 us] [Idle]
        FC → ESC                              ESC → FC
```

Maximum bidirectional update rate: ~10 kHz per motor (limited by TX+RX cycle).
At 4 kHz rate PID loop, there is ~150 us idle margin per cycle.

### DSHOT Special Commands (Throttle 0-47)

| Value | Command |
|---|---|
| 0 | Motor stop (disarmed)|
| 1-5 | Beep patterns |
| 6 | ESC info request |
| 7 | Spin direction 1 |
| 8 | Spin direction 2 |
| 12 | Save settings |
| 20 | Spin direction normal|
| 21 | Spin direction reversed |
| 42 | Enable bidirectional eRPM telemetry  |

### Bidirectional DSHOT DMA Implementation (STM32H743)

Each motor channel uses TIM1 CHx in two phases per cycle:

```
Phase 1 (TX): 53 us
  - Pin mode: alternate function (push-pull)
  - TIM1 in PWM output compare mode
  - DMA1 streams 16 timing values from TX buffer to TIM1_CCRx
  - DMA complete → switch to phase 2

Phase 2 (RX): 50 us window
  - Pin mode: alternate function (open-drain input with pull-up)
  - TIM1 in input capture mode (capture on falling edge)
  - DMA2 streams up to 21 timestamp values from TIM1_CCRx to RX buffer
  - Software decodes GCR → eRPM
```

All 4 channels share TIM1 base clock; each channel has its own DMA stream
for both TX (PWM out) and RX (input capture).

### eRPM Decoder (Pure Core)

```c
// Decode 21 GCR timestamps → 16-bit value → eRPM
typedef struct {
    uint16_t erpm;        // 12-bit eRPM
    uint16_t rpm;         // mechanical RPM (with pole_pairs scaling)
    bool valid;           // CRC matched
} dshot_telem_t;

dshot_telem_t dshot_decode(const uint16_t *capture_buf, uint8_t pole_pairs);
```

This function is in the Pure Core (deterministic, host-testable).

### Failure Modes

| Condition | Action |
|---|---|
| No GCR response (timeout) | Mark motor as offline; degrade gracefully |
| GCR CRC mismatch | Discard reading; use last valid value |
| eRPM = 0 with throttle > idle | Possible motor stall; counter starts |
| Stall counter > 100 ms | Disarm motor; transition to Diag |
| eRPM far from expected (~30%) | Possible desync; warn but continue |

## ADC — Battery, Cell, and Current Monitoring

For voltage divider component values and ADC pin assignments,
see [hardware.md](hardware.md). Conversion formulas:

| Measurement | ADC  | Formula |
|---|---|---|
| Pack voltage | ADC1 | `pack_mv = (adc_raw * 3300 * 4) / 4095` |
| Cell 1 voltage | ADC1 | `cell1_mv = (adc_raw * 3300 * 2) / 4095` |
| Cell 2 voltage | ADC1 | `cell2_mv = (adc_raw * 3300 * 4) / 4095 - cell1_mv` |
| Cell 3 voltage | -- | `cell3_mv = pack_mv - cell1_mv - cell2_mv` (3S only) |
| Motor current  | ADC3 | `current_mA = (adc_raw * 3300) / (4095 * 0.01 * 50) * 1000` |

Sample rates:
- Pack + cell ADCs: 10 Hz, 8x hardware oversampling (14-bit effective)
- Motor current ADC: 1 kHz, synchronized with PID loop

For cell voltage thresholds, balance detection, and failsafe actions,
see [safety.md](safety.md).

## SDMMC — MicroSD Card (Blackbox)

| Parameter | Value |
|---|---|
| Interface | SDMMC1 (4-bit SDIO) |
| Pins | CK, CMD, D0, D1, D2, D3 + CD (card detect) |
| Bus Width | 4-bit |
| Clock | 25-50 MHz (High Speed mode) |
| Throughput | ~12-25 MB/s |
| Filesystem | FAT32 |
| Connector | Push-push MicroSD slot on carrier board |
| DMA | SDMMC1 IDMA (built-in) |
| Zephyr Config | `CONFIG_DISK_DRIVER_SDMMC=y`, `CONFIG_FAT_FILESYSTEM_ELM=y` |

### Write Buffering

PID loop writes to a 32 KB ring buffer in DTCM (DMA-safe, no cache).
A background Zephyr thread drains the ring buffer to SD via SDMMC DMA.
SD garbage collection spikes (~10-100 ms) are absorbed by the ring buffer
(32 KB holds ~2 s of log data at 15 KB/s). PID loop never blocks on SD.

### File Naming Convention

```
/LOG00001.CSV    ← flight 1
/LOG00002.CSV    ← flight 2
...
```

New file created on arm, closed on disarm. File header contains firmware
version, date, battery voltage, and column names. See [features.md](features.md#data-logging-blackbox).

## WS2812B — RGB LED Protocol

| Parameter | Value |
|---|---|
| Data Pin | WS2812_DIN |
| Protocol | Single-wire NRZ |
| Bit 0 | 0.4 us high + 0.85 us low |
| Bit 1 | 0.8 us high + 0.45 us low |
| Reset | > 50 us low |
| Bit Order | GRB, MSB first |
| LEDs | 1 (single WS2812B on core module) |
| Implementation  | SPI MOSI via DMA (one byte per bit) or TIM PWM + DMA |

Note: Arm LEDs (direction identification) are TBD — pending voltage level
solution for WS2812B on 3.3V system. See quick_note.md.

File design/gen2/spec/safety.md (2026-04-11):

# Safety Specification (Gen 2)

## Gen 1 Issue Resolution

Every Gen 1 hardware issue is explicitly addressed in this design.

| Gen 1 Issue | Resolution in Gen 2 |
|---|---|
| HW-01 Missing gate pull-downs | Eliminated: using 4-in-1 ESC (built-in gate control) |
| HW-02 No reverse polarity | Added: P-FET reverse polarity protection |
| HW-03 No overcurrent | Added: PTC resettable fuse (3A hold / 6A trip) |
| HW-04 Missing LC filter | Added: LC filter on battery input (4.7 uH + 100 uF) |
| HW-05 Missing gate resistors | Eliminated: ESC handles gate drive internally  |
| HW-06 No ESD protection | Added: TVS on USB-C (USBLC6-2SC6), TVS on SWD |
| HW-07 DRC violations | Addressed: 4-layer PCB resolves trace width and thermal issues |
| HW-08 IMU/BT power sequence  | Addressed: separate enable control; IMU powers on after 200 ms delay |
| HW-09 BOOT0 jumper usability | Replaced: USB-C DFU via software button hold |
| HW-10 Cannot power off | Fixed: high-side P-FET switch with clean cutoff |
| HW-11 Overweight (74g) | Fixed: 141g AUW with 800g thrust (T/W 5.7:1) |
| HW-12 BT/IMU interference | Fixed: IMU at board center, BLE at edge, ground plane shielding |
| HW-13 LDO inefficient | Replaced: TPS63070 buck-boost (93% vs 45% efficiency) |

## Power Safety

### Battery Protection

| Requirement | Status | Implementation |
|---|---|---|
| Reverse polarity protection  | Present | P-FET (DMP2035U) on battery input |
| Over-voltage protection | Present | 3S LiPo max 12.6V within TPS63070 input range |
| Under-voltage cutoff | Present | Firmware: 3.0V/cell cutoff, motors off immediately |
| Over-current protection | Present | PTC fuse: 5A hold / 10A trip |
| Short circuit protection | Present | PTC fuse + battery BMS |
| Charge protection | N/A | External balance charger handles CV/CC/termination |

### Low Battery Thresholds (Per-Cell, 3S)

All thresholds are defined per-cell and applied to the 3S pack.

| Level | Per-Cell V  | Enter At | Exit At | 3S Pack | Action |
|---|---|---|---|---|---|
| Normal | > 3.5V | -- | -- | > 10.5V | Normal operation |
| Warning  | 3.3-3.5V | 3.5V | 3.6V | 10.5V/10.8V| LED orange, buzzer/2s, telemetry |
| Critical | 3.0-3.3V | 3.3V | 3.4V | 9.9V/10.2V | Ramp motors to 0, → Diag, LED red, buzzer rapid |
| Cutoff | < 3.0V | 3.0V | -- | 9.0V | Motors off immediately, remain in Diag |

Note: Hysteresis (100 mV per cell) prevents oscillation near thresholds.

Thresholds are evaluated **per individual cell** (via balance connector
monitoring), not just the pack average. Any single cell falling below
threshold triggers the corresponding action. See
[hardware.md](hardware.md#per-cell-voltage-monitoring).

### Cell Imbalance Detection

| Condition | Action |
|---|---|
| Max cell - min cell > 50 mV (warning)  | LED flash, telemetry warning |
| Max cell - min cell > 100 mV (error) | Refuse arm; require recharge / balance|
| Max cell - min cell > 200 mV in flight | Critical: ramp motors to 0, → Diag |

Imbalance indicates a damaged cell or improper charging. Refusing arm
prevents flight on a battery that may suddenly sag below cutoff under load.

### Input Power Filtering

| Component | Value | Purpose |
|---|---|---|
| L1 (inductor)| 4.7 uH | Filter motor PWM noise from battery rail |
| C_FILT | 100 uF MLCC | Low-impedance bulk filter |
| Location | Between PTC fuse and ESC/regulator input | |

## Motor Safety

### ESC Safety Features

| Requirement | Status | Implementation |
|---|---|---|
| Motors off on power-up | Present | ESC requires DSHOT arm sequence; no output until armed |
| Arm/disarm required | Present | AUX1 channel (CH5) arm switch  |
| Bidirectional DSHOT300 | Present | BlueJay firmware on ESC; eRPM telemetry per motor |
| ESC desync protection | Present | BlueJay firmware handles desync |
| Motor stall detection (RPM) | Present | Bidirectional DSHOT eRPM (primary) |
| Motor stall detection (current) | Present | Shunt + op-amp (secondary, redundancy) |

### Motor RPM Monitoring (Primary Stall Detection)

| Parameter | Value |
|---|---|
| Source | Bidirectional DSHOT300 eRPM (per motor) |
| Update Rate | 4 kHz (every rate PID cycle) |
| Resolution | 12-bit eRPM (~0.1% at typical RPMs) |
| Pole Pairs | 7 (for 1404 motors with 14 magnets) |
| RPM Range | 0 - 50,000 RPM (3S 1404) |
| Stall Detection | eRPM = 0 with DSHOT throttle > 200 for > 100 ms |
| Desync Detection | eRPM deviation > 30% from expected for > 200 ms |
| Action on Stall | Disarm all motors, → Diag, report error |
| Action on Desync | Warn but continue; log event |

### Motor Current Monitoring (Secondary, Backup)

| Parameter | Value |
|---|---|
| Sense Resistor | 10 mohm per motor (on ESC output) |
| Op-Amp Gain | 50x (external op-amp on carrier) |
| Over-current Threshold | 5 A per motor (software limit) |
| Use | Backup stall detection if RPM telemetry fails |
| Action on Overcurrent  | Affected motor DSHOT = 0; → Diag |

### Failsafe Conditions

| Condition | Detection | Action |
|---|---|---|
| ELRS link loss (alt < 2 m) | No valid CRSF > 500 ms | Ramp motors to 0 over 200 ms; → Diag |
| ELRS link loss (alt >= 2 m) | No valid CRSF > 500 ms | **AUTO_LAND**: descend 0.5 m/s, position hold (OF/GPS), land; → Diag |
| IMU failure (no INT1) | No INT1 pulse > 10 ms  | Ramp motors to 0 over 200 ms; → Diag |
| Low battery critical (< 3.3V) | ADC threshold | Ramp motors to 0 over 200 ms; → Diag |
| Low battery cutoff (< 3.0V) | ADC threshold | Motors off immediately; remain in Diag |
| Watchdog timeout | IWDG hardware | MCU reset → full startup sequence |
| Excessive tilt (> 60 deg) | IMU angle calculation | Motors off immediately; → Diag |
| PID tilt limit (45 deg) | PID saturation | PID output clamped; no further tilt |
| Motor stall detected | DSHOT eRPM = 0 with thr > 200 for 100 ms | Motors off immediately; → Diag |
| Motor overcurrent (> 5 A) | Current sensing (backup)| Affected motor DSHOT = 0; → Diag |
| Motor desync detected | DSHOT eRPM > 30% off expected | Warn; continue flight |
| ESC bidirectional DSHOT failure| No GCR response for > 1 s | Fall back to current-only stall detection |
| Cell imbalance (> 100 mV) | Per-cell ADC monitoring | Refuse arm; warn user |
| Cell critical imbalance (> 200 mV in flight) | Per-cell ADC | Ramp motors to 0; → Diag |
| BLE disconnect | UART timeout | No flight action (BLE is not flight-critical)|

## EMI / Signal Integrity

| Requirement | Status | Implementation |
|---|---|---|
| Input LC filter (battery) | Present | 4.7 uH + 100 uF on battery input |
| Continuous ground plane | Present | 4-layer: L2 = unbroken GND plane |
| IMU placement isolation | Present | Board center, local GND pour, away from power traces |
| BLE antenna separation | Present | BLE module at board edge, >= 10 mm from IMU |
| BLE ground keepout | Present | No copper under antenna per module datasheet |
| SPI signal integrity | Present | Short traces (< 20 mm); series termination 33 ohm on SCK if needed |
| Decoupling on all VDD pins | Present | 100 nF on each VDD pin (0402)  |
| Shielded inductor (buck-boost) | Present | Shielded 1 uH to minimize radiated EMI |
| Motor power routing (bottom layer) | Present | High-current motor traces on L4, away from analog on L1 |

## ESD Protection

| Interface | Protection | Device / Method |
|---|---|---|
| USB-C (D+/D-) | TVS diode array | USBLC6-2SC6 (SOT-23-6) |
| USB-C (VBUS) | TVS + PTC fuse | No battery charging; USB powers core module only |
| SWD (SWDIO/SWCLK) | TVS diode array | PRTR5V0U2X (SOT-363) |
| Battery connector  | PTC fuse + P-FET | No direct ESD path to ICs  |
| ELRS RX pads | Internal to module | Module handles ESD |
| BLE module pads | Internal to module | Module handles ESD |

## Thermal Safety

| Component | Max Temp | Estimated Rise | Margin  |
|---|---|---|---|
| STM32H743 (480 MHz)  | 105 C | ~15 C above ambient | 50+ C |
| TPS63070 (400 mA) | 150 C | ~8 C above ambient | 90+ C |
| ESC MOSFETs (hover)  | 150 C | ~20 C above ambient | 80+ C |

No active cooling required. All components operate well within thermal limits
at maximum load in 40 C ambient.

## Software Safety

### Watchdog

| Parameter | Value |
|---|---|
| Type | Independent Watchdog (IWDG) |
| Clock | LSI (~32 kHz) |
| Timeout | 100 ms |
| Refresh | Every rate PID loop iteration  |
| On Timeout | MCU hardware reset → full startup |

### Stack Overflow Protection

| Parameter | Value |
|---|---|
| MPU Region | Stack guard (4 bytes, no access)|
| Detection | MemManage fault → MCU reset |
| Stack Size | Main: 2 KB, ISR: 1 KB (Zephyr configured) |

### D-Cache Coherency (H743 Specific)

| Concern | Mitigation |
|---|---|
| DMA + D-cache stale data | Use DTCM (no cache) for all DMA buffers |
| Alternative | Cache-aligned buffers + SCB_CleanDCache_by_Addr() before DMA TX, SCB_InvalidateDCache_by_Addr() after DMA RX |
| MPU configuration | Mark DMA buffer regions as non-cacheable via MPU |

### DMA Safety

| Concern | Mitigation |
|---|---|
| DMA overrun | Double-buffering on IMU SPI DMA |
| DMA error | DMA error interrupt → flag fault, disable motors |
| Buffer corruption | DMA buffers in dedicated SRAM section, not shared |

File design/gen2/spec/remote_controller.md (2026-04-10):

# Remote Controller Specification (Gen 2)

## Architecture Overview

Gen 2 uses a dual-link communication architecture:

| Link | Protocol | Purpose | Latency  | Rate |
|---|---|---|---|---|
| **Primary**  | ELRS (CRSF) | Real-time flight control | 2 - 5 ms | 50-500 Hz |
| **Secondary**| BLE 5.0 | Config, telemetry, OTA, blackbox | 15-30 ms | 10 Hz |

ELRS handles all time-critical stick inputs and flight mode switching.
BLE handles configuration, PID tuning, blackbox download, and OTA updates.
If BLE disconnects during flight, there is no impact on flight control.

## Primary Link: ExpressLRS (ELRS)

### Transmitter (TX) — Recommended Hardware

| Option | Price | Form Factor | ELRS Built-in | Notes |
|---|---|---|---|---|
| RadioMaster Pocket | ~$60 | Compact gamepad| Yes (2.4 GHz)  | Best value, portable |
| RadioMaster Zorro | ~$90 | Full gimbals | Yes (2.4 GHz)  | Better gimbals |
| RadioMaster Boxer | ~$120 | Full-size TX | Yes (2.4 GHz)  | Most ergonomic |
| BetaFPV LiteRadio 3  | ~$40 | Compact gamepad| Yes (2.4 GHz)  | Budget option |

All recommended TXs run **EdgeTX** open-source firmware with native ELRS support.

### Receiver (RX) — On Drone

| Option | Weight | Size | Antenna | Notes |
|---|---|---|---|---|
| **BetaFPV ELRS Lite RX** | 0.5 g | 10x10 mm  | Ceramic | Lightest, recommended |
| HappyModel EP2 | 0.9 g  | 12x12 mm  | Wire dipole| Better range |
| HappyModel PP | 0.4 g  | 10x10 mm  | Ceramic | Ultra-light |

Recommended: **BetaFPV ELRS Lite RX** for best weight/performance balance.

### ELRS Configuration

| Parameter | Value |
|---|---|
| Frequency | 2.4 GHz |
| TX Power | 25 mW (indoor) / 100 mW (outdoor) |
| Packet Rate | 250 Hz (recommended default) |
| Switch Mode | Hybrid 8-channel (8 proportional channels) |
| Telemetry Ratio | 1:8 (one telemetry packet per 8 RC packets) |
| Bind Phrase | Configured via ExpressLRS Configurator (no physical bind button needed) |

### Packet Rate vs Latency Trade-off

| Packet Rate | Latency | Range (25 mW) | Channels | Best For |
|---|---|---|---|---|
| 50 Hz | 20 ms | 30+ km | 12 | Long range (unused)|
| 150 Hz | 6.6 ms  | 10+ km | 12 | Outdoor cruising |
| 250 Hz | 4 ms | 5+ km | 8 | **Default indoor** |
| 500 Hz | 2 ms | 2+ km | 4 | Racing (aggressive)|

Recommended: **250 Hz** for indoor use (4 ms latency, 8 channels sufficient).

### Channel Assignment (EdgeTX Mixer)

| Channel | EdgeTX Input | Function | Endpoints |
|---|---|---|---|
| CH1 | Aileron (A)  | Roll | 172 - 1811 |
| CH2 | Elevator (E) | Pitch | 172 - 1811 |
| CH3 | Throttle (T) | Throttle | 172 - 1811 |
| CH4 | Rudder (R) | Yaw | 172 - 1811 |
| CH5 | SA (2-pos) | Arm / Disarm | 172 / 1811 |
| CH6 | SB (3-pos) | Flight Mode | 172/992/1811  |
| CH7 | SC (2-pos) | Position Hold | 172 / 1811 |
| CH8 | SD (2-pos) | Buzzer / Beeper  | 172 / 1811 |

### ELRS Failsafe Configuration

| Setting | Value |
|---|---|
| Failsafe Mode | No Pulses (CRSF stops sending) |

For FC-side failsafe detection and actions, see [safety.md](safety.md#failsafe-conditions).

### ELRS Bind Procedure

1. Power on drone while double-pressing SW1 → drone enters bind mode (LED purple blink)
2. On TX: enter ELRS Lua script → select "Bind"
3. TX and RX exchange bind phrase
4. LED changes to blue (bound, in Diag mode)
5. Bind phrase stored in ELRS RX flash; persists across power cycles

Alternative: use ExpressLRS Configurator to pre-flash a bind phrase to both
TX module and RX. No runtime bind procedure needed.

## Secondary Link: BLE 5.0

### Phone App

| Platform | Framework | Features |
|---|---|---|
| iOS | Swift / SwiftUI | Config, telemetry, blackbox viewer  |
| Android | Kotlin / Compose| Same features as iOS |
| Cross-platform | Flutter | Single codebase for both |

Recommended: **Flutter** for cross-platform development.

### BLE GATT Service Layout

| Service | UUID (16-bit) | Description |
|---|---|---|
| Drone Control Service | 0xDC01 | Configuration and commands |
| Telemetry Service | 0xDC02 | Real-time sensor data streaming  |
| Blackbox Service | 0xDC03 | Flight log download |
| DFU Service | 0xFE59 | Nordic DFU (standard UUID) |

#### Drone Control Service (0xDC01)

| Characteristic | UUID | Properties | Description |
|---|---|---|---|
| PID Gains | 0xDC11 | R/W | Read/write PID gains (36 bytes: 3 axes x 2 loops x 3 gains x float) |
| Flight Config | 0xDC12 | R/W | Max tilt angle, throttle curve, etc. |
| Device Info | 0xDC13 | R | FW version, HW revision, serial |
| Command | 0xDC14 | W | Send commands (calibrate, find-me, erase blackbox) |
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

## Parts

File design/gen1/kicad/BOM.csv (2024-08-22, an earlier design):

Reference | Value | Datasheet | Footprint | Qty | DNP
C1,C3,C4,C6 | 10 uF | ~ | Capacitor_SMD:C_1210_3225Metric_Pad1.33x2.70mm_HandSolder | 4
C2,C5,C7,C9,C10,C11,C12 | 0.1 uF | ~ | Capacitor_SMD:C_0603_1608Metric_Pad1.08x0.95mm_HandSolder | 7
C8 | 1 uF | ~ | Capacitor_SMD:C_0603_1608Metric_Pad1.08x0.95mm_HandSolder | 1
C13,C15 | 20 pF | ~ | Capacitor_SMD:C_0603_1608Metric_Pad1.08x0.95mm_HandSolder | 2
C14,C16 | 12 pF | ~ | Capacitor_SMD:C_0603_1608Metric_Pad1.08x0.95mm_HandSolder | 2
D1,D2,D3,D4,D9,D10 | LED | ~ | -- 混合值 -- | 6
D5,D6,D7,D8 | 1N4007 | http://www.vishay.com/docs/88503/1n4001.pdf | Diode_SMD:D_SMA | 4
J1,J5 | BAT | ~ | Connector_PinHeader_2.54mm:PinHeader_1x02_P2.54mm_Horizontal | 2
J2 | HM-13 Bluetooth | ~ | Connector_PinSocket_2.54mm:PinSocket_1x04_P2.54mm_Vertical | 1
J3 | programming | ~ | Connector_PinHeader_2.54mm:PinHeader_1x06_P2.54mm_Vertical | 1
J4 | mpu6050 | ~ | Connector_PinSocket_2.54mm:PinSocket_1x04_P2.54mm_Vertical | 1
J6 | place_holder | ~ | Connector_PinHeader_2.54mm:PinHeader_1x02_P2.54mm_Vertical | 1
J7 | Conn_02x04_Odd_Even | ~ | Connector_PinHeader_2.54mm:PinHeader_2x04_P2.54mm_Vertical | 1
J8 | J-Link | ~ | Connector_PinHeader_2.54mm:PinHeader_1x04_P2.54mm_Horizontal | 1
J9,J10 | Conn_01x20 | ~ | Connector_PinHeader_2.54mm:PinHeader_1x20_P2.54mm_Vertical | 2
J11 | jumper | ~ | Connector_PinHeader_2.54mm:PinHeader_1x02_P2.54mm_Vertical | 1
M1 | BR | ~ | Connector_PinHeader_2.54mm:PinHeader_1x02_P2.54mm_Horizontal | 1
M2 | BL | ~ | Connector_PinHeader_2.54mm:PinHeader_1x02_P2.54mm_Horizontal | 1
M3 | FR | ~ | Connector_PinHeader_2.54mm:PinHeader_1x02_P2.54mm_Horizontal | 1
M4 | FL | ~ | Connector_PinHeader_2.54mm:PinHeader_1x02_P2.54mm_Horizontal | 1
Q1,Q2,Q3,Q4 | SI2302 |  | si2302_kicad:SOT23 | 4
R1,R6 | 30 K | ~ | Resistor_SMD:R_0603_1608Metric | 2
R2,R3,R4,R5 | 180 | ~ | Resistor_SMD:R_0603_1608Metric | 4
R7,R8,R9,R10,R11,R12,R14,R15 | 10 K | ~ | Resistor_SMD:R_0603_1608Metric | 8
R13,R16 | 1 K | ~ | Resistor_SMD:R_0603_1608Metric | 2
R17,R18 | 100 K | ~ | Resistor_SMD:R_0603_1608Metric | 2
SW1 | SW_DIP_x02 | ~ | Button_Switch_SMD:SW_DIP_SPSTx02_Slide_Omron_A6H-2101_W6.15mm_P1.27mm | 1
SW2 | SW_Push | ~ | Button_Switch_SMD:SW_SPST_TL3342 | 1
SW3 | V_sw | ~ | Button_Switch_THT:SW_CK_JS202011CQN_DPDT_Straight | 1
U1 | LM1117MP-3.3 | http://www.ti.com/lit/ds/symlink/lm1117.pdf | Package_TO_SOT_SMD:SOT-223-3_TabPin2 | 1
U2 | STM32F103CBTx | https://www.st.com/resource/en/datasheet/stm32f103cb.pdf | Package_QFP:LQFP-48_7x7mm_P0.5mm | 1
Y1 | 8MHz | ~ | Crystal:Crystal_SMD_3225-4Pin_3.2x2.5mm_HandSoldering | 1
Y2 | 32,768KHz | ~ | Crystal:Crystal_SMD_3215-2Pin_3.2x1.5mm | 1
BAT | 560mAh |  | Desire Power 3.7v 560mAh 35C | 2

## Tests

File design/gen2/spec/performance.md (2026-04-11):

# Performance Specification (Gen 2)

## Flight Performance (Target)

| Parameter | Target Value | Notes |
|---|---|---|
| Flight Time (hover) | ~26 min | CNHL 3S 850mAh, 141g AUW |
| Flight Time (mixed) | ~18 min | Hover + mild maneuvering |
| Max Thrust | ~800 g | 4x 1404 @ 3S, 3" props |
| Thrust-to-Weight | 5.7 : 1 | At 141g AUW — see [mechanical.md](mechanical.md) |
| Max Payload | ~100 g | T/W 3.3:1 with payload |
| PID Tilt Limit | 45 deg | PID output saturates |
| Emergency Tilt Cutoff  | 60 deg | Motors off immediately |
| Max Altitude (indoor)  | 4 m | Limited by VL53L5CX ToF range  |
| Max Altitude (outdoor) | ~30 m | Barometer limited, no GPS |
| Position Hold Accuracy | +/- 20 cm | Optical flow, indoor, calm air |
| Altitude Hold Accuracy | +/- 15 cm | Baro + ToF fusion |

## Control Loop

| Parameter | Target Value | Notes |
|---|---|---|
| IMU Sample Rate | 8000 Hz | ICM-42688 via SPI + INT1 |
| Rate PID Loop | 4000 Hz | Inner loop (gyro rate) |
| Angle PID Loop | 1000 Hz | Outer loop (attitude angle) |
| Altitude Loop | 50 Hz | Baro + ToF fusion update |
| Position Loop | 50 Hz | Optical flow update |
| DSHOT Output Rate | 4000 Hz | Matches rate PID loop |
| CRSF Input Rate | 50 - 500 Hz | Depends on ELRS packet rate |
| BLE Telemetry Rate | 10 Hz | Non-critical, background |
| Blackbox Log Rate | 1000 Hz (configurable)| Matches angle PID loop |

### Cascaded PID Architecture

```
ELRS Stick Input
      |
      v
 +----------+    +----------+    +--------+    +-------+
 | Setpoint  |--->| Angle    |--->| Rate   |--->| Motor |
 | Mapping   |    | PID      |    | PID    |    | Mixer |
 |           |    | (1 kHz)  |    | (4 kHz)|    |       |
 +----------+    +----------+    +--------+    +-------+
                      ^               ^             |
                      |               |             v
                 IMU Angle        IMU Rate      DSHOT Out
               (complementary    (gyro raw)    (4x motors)
                filter)
```

## Response Time

| Event | Max Latency |
|---|---|
| IMU read to rate PID output | < 0.25 ms |
| IMU read to angle PID output  | < 1 ms |
| CRSF frame to PID setpoint | < 2 ms |
| CRSF failsafe detection | 500 ms (no valid frame) |
| IMU failure detection | 10 ms (no INT1 pulse) |
| Failsafe ramp-down complete | 200 ms from detection |
| Battery ADC update | 100 ms |
| Motor current ADC update | 1 ms (per PID loop) |
| Altitude sensor update | 20 ms |
| Optical flow update | 20 ms |
| BLE command to action | < 50 ms |
| USB DFU: full flash (128 KB)  | < 5 s |

## Power Budget

### Digital Subsystem (3.3V Rail)

| Component | Current (mA) | Power (mW) |
|---|---|---|
| STM32H743 @ 480 MHz | 300 | 990 |
| ICM-42688-P (LN mode)  | 0.8 | 2.6 |
| BMP390 (normal mode) | 0.7 | 2.3 |
| VL53L5CX (ranging) | 18 | 59 |
| PMW3901 (tracking) | 8 | 26 |
| nRF52 BLE (TX active)  | 10 | 33 |
| ELRS Lite RX | 40 | 132 |
| WS2812B LED (white) | 20 | 66 |
| Buzzer (active) | 30 | 99 |
| **Subtotal (typical)** | **~398** | **~1313**  |
| **Subtotal (max)** | **~428** | **~1412**  |

### Buck Regulator (TPS63070)

| Parameter | Value |
|---|---|
| Input Voltage | 9.0 - 12.6V (3S)  |
| Output Voltage | 3.3V |
| Mode | Buck |
| Load Current (typical) | ~398 mA |
| Efficiency | ~89% |
| Power Dissipation | ~163 mW |
| Input Current from Battery | ~126 mA |

### Motor Subsystem — 1404 4500KV on 3S

| Condition | Current/Motor | Total 4x | Battery Power |
|---|---|---|---|
| Idle (DSHOT 48) | 40 mA | 160 mA | 1.8 W |
| Hover (~15% throttle) | 350 mA | 1.4 A | 15.5 W |
| Sport (~40% throttle) | 1.2 A | 4.8 A | 53.3 W |
| Full throttle (100%) | 5.0 A | 20.0 A | 222 W |

### Total System Power (Hover)

| Motor Hover (W) | Digital (W) | Reg Loss (W) | **Total (W)** |
|---|---|---|---|
| 15.5 | 1.31 | 0.16 | **17.0** |

### Flight Time Estimates

Battery: CNHL 3S 850 mAh, 11.1V = 9.44 Wh (7.55 Wh usable at 80%), AUW ~141 g

| Flight Mode | Total Power | Flight Time |
|---|---|---|
| Gentle hover | 17.0 W | **26.6 min** |
| Mixed flying | 25 W | **18.1 min** |
| Aggressive | 53 W | **8.5 min** |

### Summary

| Parameter | Value |
|---|---|
| Battery | CNHL 3S 850mAh 70C |
| AUW | ~141 g |
| Max Thrust | ~800 g |
| Thrust-to-Weight | 5.7 : 1 |
| Max Payload | ~100 g (T/W 3.3:1) |
| Hover Time | 26.6 min |
| Mixed Flight Time | 18.1 min |
| Best For | Indoor / Outdoor |

For detailed weight breakdown, see [mechanical.md](mechanical.md).

### Alternative Battery Options

| Battery | Energy | Weight | AUW | Hover Time | Mixed Time |
|---|---|---|---|---|---|
| CNHL 3S 450mAh 70C | 5.0 Wh | 40 g | ~101 g | 17.6 min | 12.0 min |
| **CNHL 3S 850mAh 70C** | **9.44 Wh** | **80 g** | **~141 g** | **26.6 min** | **18.1 min** |
| CNHL 3S 1300mAh 70C  | 14.4 Wh  | 120 g  | ~181 g | 33 min | 22 min |

## Regulator Thermal

| Parameter | Value |
|---|---|
| Regulator | TPS63070 |
| Input Voltage | 2.0 - 16V |
| Output Voltage | 3.3V |
| Efficiency (worst case 3S) | ~88% |
| Load Current | ~398 mA |
| Power Dissipation (worst)  | ~180 mW (3S input, ~88% eff) |
| Thermal Resistance | ~45 C/W (VQFN-14 to PCB) |
| Temperature Rise | ~8 C |

Note: Acceptable thermal. Higher than G431 design but well within TPS63070's 2A capability.

## Processing Budget

<!-- STM32H743 @ 480 MHz, Cortex-M7 dual-issue superscalar -->

| Task | CPU Cycles (est.) | Period  | CPU Load |
|---|---|---|---|
| Rate PID (3-axis) | 1000 | 0.25 ms | 0.83% |
| Angle PID (3-axis) | 1500 | 1 ms | 0.31% |
| IMU SPI read + process  | 500 | 0.125 ms| 0.83% |
| Motor mixer + DSHOT DMA | 300 | 0.25 ms | 0.25% |
| CRSF parse | 200 | 2 ms | 0.02% |
| Baro read + altitude | 800 | 20 ms | 0.008% |
| Optical flow read | 400 | 20 ms | 0.004% |
| BLE UART TX | 200 | 100 ms  | 0.0004%  |
| Blackbox flash write | 500 | 1 ms | 0.10% |
| Battery ADC | 100 | 100 ms  | 0.0002%  |
| LED update | 200 | 50 ms | 0.0008%  |
| **Total** | | | **~3%**  |

Headroom: ~97% CPU idle at 480 MHz. Enables future EKF sensor fusion, computer vision preprocessing, and companion computer protocol handling.

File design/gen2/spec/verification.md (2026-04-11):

# Verification Architecture (Gen 2)

## 1. Provable Properties Catalog

Properties are classified as **formally provable** (P) or **test-only** (T) based
on whether the logic is deterministic and side-effect-free.

### 1.1 Safety Properties (Must Prove)

| ID | Property | Class | Tool |
|---|---|---|---|
| VP-01 | State machine never reaches an undefined state | P | TLA+ |
| VP-02 | Motors DSHOT = 0 in any state other than Running/armed| P | TLA+ |
| VP-03 | Calibrate → Diag only on success; never Calibrate → Running | P | TLA+ |
| VP-04 | Disarm from Running always reaches Diag within finite steps | P | TLA+ |
| VP-05 | Battery cutoff (< 3.0V) forces motors off in all states | P  | TLA+ |
| VP-06 | Rate PID integrator |value| <= WINDUP_MAX at all times | P | CBMC  |
| VP-07 | Angle PID integrator |value| <= WINDUP_MAX at all times | P | CBMC |
| VP-08 | Motor DSHOT throttle <= 2047 for all inputs | P | CBMC |
| VP-09 | No arithmetic overflow in PID calculation (int16 inputs, float intermediates) | P | CBMC |
| VP-10 | CRSF stick center (992) produces exactly zero setpoint | P | CBMC |
| VP-11 | Voltage divider ADC-to-mV conversion never overflows uint16 (30K/10K divider, up to 12.6V) | P | CBMC |
| VP-11a| Cell count detection returns 1, 2, or 3 for all valid voltage ranges; returns ERROR for dead zone (4.4-6.0V) | P | CBMC |
| VP-12 | Motor stall detection triggers disarm in all states | P | TLA+ |
| VP-13 | Error mode is absorbing: only exit is watchdog reset  | P | TLA+ |

### 1.2 Liveness Properties (Must Prove)

| ID | Property | Class | Tool |
|---|---|---|---|
| VP-14 | System always eventually exits Calibrate (success or timeout) | P | TLA+ |
| VP-15 | Motor ramp-down completes within duration_ms | P | TLA+ |
| VP-16 | Watchdog is refreshed at least once per 100 ms | P | TLA+ |
| VP-17 | CRSF failsafe activates within 500 ms of link loss | P | TLA+ |

### 1.3 Protocol Properties (Must Prove)

| ID | Property | Class | Tool |
|---|---|---|---|
| VP-18 | CRSF parser always terminates (no infinite loop) | P | CBMC |
| VP-19 | CRSF parser output is empty OR has valid channels | P | CBMC |
| VP-20 | CRSF parser discards frames with bad CRC | P | CBMC |
| VP-21 | CRSF parser buffer never reads/writes out of bounds | P | CBMC |
| VP-22 | BLE protocol parser always terminates | P | CBMC |
| VP-23 | BLE protocol parser rejects invalid checksum | P | CBMC |
| VP-24 | BLE protocol parser buffer never overflows | P | CBMC |

### 1.4 Additional Provable Properties

| ID | Property | Class | Tool |
|---|---|---|---|
| VP-25 | Battery level hysteresis: per-cell warning enter 3.5V, exit 3.6V; critical enter 3.3V, exit 3.4V; applied to 3S pack | P | CBMC |
| VP-26 | Calibration variance check rejects samples with stddev > threshold | P | CBMC |
| VP-27 | Arm debounce rejects re-arm when elapsed_ms < 1000 | P | CBMC |
| VP-28 | Motor mixer output clamped to [0, 2047] for all inputs| P | CBMC |
| VP-29 | Motor mixer never produces negative duty values | P | CBMC |
| VP-30 | CRSF channel value mapping stays within defined ranges | P | CBMC |
| VP-31 | Altitude estimator fusion weight transitions smoothly at crossfade zone | P | CBMC |
| VP-32 | Pre-flight checks: all conditions must pass for arm to succeed | P | TLA+ |
| VP-33 | DSHOT CRC is correct for all throttle values (0-2047) | P | CBMC |
| VP-34 | Complementary filter output is bounded for bounded inputs | P | CBMC |

### 1.5 Testable-Only Properties

| ID | Property | Class | Tool |
|---|---|---|---|
| VT-01 | IMU WHO_AM_I returns 0x47 on valid hardware | T | Ztest |
| VT-02 | BMP390 CHIP_ID returns 0x60 on valid hardware | T | Ztest |
| VT-03 | VL53L5CX firmware upload completes within 500 ms | T | Ztest+HW |
| VT-04 | PMW3901 Product_ID returns 0x49 | T | Ztest |
| VT-05 | SPI bus recovery succeeds after MISO stuck | T | Ztest+HW |
| VT-06 | I2C bus recovery succeeds after SDA stuck low | T | Ztest+HW |
| VT-07 | ELRS link established within 5 s of TX power-on | T | Ztest+HW |
| VT-08 | BLE advertising starts within 1 s of boot | T | Ztest+HW |
| VT-09 | LED patterns match mode (visual / GPIO check) | T | Ztest |
| VT-10 | Rate PID loop timing meets 4 kHz +/- 2% on target HW | T | Ztest+HW |
| VT-11 | Angle PID loop timing meets 1 kHz +/- 5% on target HW| T | Ztest+HW |
| VT-12 | Motor test pulse duration is 500 ms +/- 10% | T | Ztest+HW |
| VT-13 | DSHOT signal timing meets spec (bit 0/1 widths) | T | Logic analyzer |
| VT-14 | Telemetry messages arrive at specified rates | T | Ztest |
| VT-15 | Blackbox write does not increase PID loop jitter > 2% | T | Ztest+HW |
| VT-16 | USB DFU mode entered successfully via SW1 hold | T | Ztest+HW |
| VT-17 | OTA update completes successfully end-to-end | T | Ztest+HW |
| VT-18 | Altitude hold accuracy +/- 15 cm in static hover | T | Flight test|
| VT-19 | Position hold accuracy +/- 20 cm in static hover | T | Flight test|
| VT-20 | Motor current measurement accuracy +/- 10% | T | Bench test |

---

## 2. Purity Boundary Map

The architecture is split into a **deterministic pure core** (formally verifiable)
and an **effectful shell** (tested only).

```
+----------------------------------------------------------------------+
|                        Effectful Shell                                |
|                                                                      |
|  +------------------+  +---------------+  +----------------------+   |
|  | CRSF Backend     |  | SPI Driver    |  | DSHOT DMA HAL        |   |
|  | (UART RX → parse |  | (ICM-42688,   |  | (TIM1 CH1-4 DMA     |   |
|  |  → drone_cmd_t)  |  |  Flash, OF)   |  |  motor output)       |   |
|  +--------+---------+  +-------+-------+  +----------+-----------+   |
|           |                     |                     ^              |
|  +------------------+  +---------------+  +----------+-----------+   |
|  | BLE Backend      |  | I2C Driver    |  | WS2812B DMA HAL      |   |
|  | (UART ↔ nRF52    |  | (BMP390,      |  | (LED output)         |   |
|  |  → drone_cmd_t)  |  |  VL53L5CX)    |  |                      |   |
|  +--------+---------+  +-------+-------+  +----------------------+   |
|           |                     |                                    |
|  +------------------+  +---------------+  +----------------------+   |
|  | USB CDC / DFU    |  | ADC HAL       |  | GPIO HAL             |   |
|  | (debug console,  |  | (battery,     |  | (buzzer, button)     |   |
|  |  firmware update) |  |  motor current)|  |                     |   |
|  +--------+---------+  +-------+-------+  +----------------------+   |
|           |                     |                                    |
+----------------------------------------------------------------------+
            |                     |                   |
            v                     v                   |
+----------------------------------------------------------------------+
|                        Pure Core                                     |
|                                                                      |
|  +------------------+  +-------------------+  +------------------+   |
|  | Command Dispatch |  | Rate PID (3-axis) |  | State Machine    |   |
|  | (drone_cmd_t,    |  | (setpoint, rate,  |  | (event, state →  |   |
|  |  mode → event)   |  |  dt → output)     |  |  next_state,     |   |
|  +------------------+  +-------------------+  |  actions[])      |   |
|                        +-------------------+  +------------------+   |
|                        | Angle PID (2-axis)|                         |
|                        | (setpoint, angle, |                         |
|                        |  dt → rate_sp)    |                         |
|                        +-------------------+                         |
|                                                                      |
|  +------------------+  +-------------------+  +------------------+   |
|  | CRSF Parser      |  | Battery Level     |  | Calibration Math |   |
|  | (bytes[] →       |  | (mV → enum        |  | (samples[] →     |   |
|  |  channels[16])   |  |  w/ hysteresis)   |  |  offsets[])      |   |
|  +------------------+  +-------------------+  +------------------+   |
|                                                                      |
|  +------------------+  +-------------------+  +------------------+   |
|  | BLE Protocol     |  | Input Mapper      |  | Motor Mixer      |   |
|  | Parser (bytes[]  |  | (CRSF channels →  |  | (throttle, PID → |   |
|  |  → ble_msg_t)    |  |  stick struct)    |  |  dshot[4])       |   |
|  +------------------+  +-------------------+  +------------------+   |
|                                                                      |
|  +------------------+  +-------------------+  +------------------+   |
|  | Attitude         |  | Altitude          |  | Position         |   |
|  | Estimator        |  | Estimator         |  | Estimator        |   |
|  | (accel, gyro, dt |  | (baro, tof, dt →  |  | (flow, alt, dt → |   |
|  |  → pitch,roll,yaw)|  |  altitude_cm)    |  |  vel_x, vel_y)   |   |
|  +------------------+  +-------------------+  +------------------+   |
|                                                                      |
|  +------------------+  +-------------------+                         |
|  | DSHOT Encoder    |  | Pre-flight Check  |                         |
|  | (throttle →      |  | (sensors, battery,|                         |
|  |  dshot_frame[16])|  |  link → pass/fail)|                         |
|  +------------------+  +-------------------+                         |
|                                                                      |
+----------------------------------------------------------------------+
```

### 2.1 Pure Core Modules

| Module | Inputs | Outputs |
|---|---|---|
| **State Machine** | current_state, event | next_state, action_list |
| **Command Dispatch**  | drone_cmd_t, current_mode | drone_event_t or IGNORE |
| **Rate PID** (x3) | setpoint, gyro_rate, dt, gains | control_output (float) |
| **Angle PID** (x2) | setpoint, est_angle, dt, gains | rate_setpoint (float) |
| **CRSF Parser** | byte_buffer[], length | crsf_channels[16] (uint16)  |
| **BLE Protocol Parser**| byte_buffer[], length | ble_msg_t or EMPTY |
| **Input Mapper** | crsf_channels[16] | drone_cmd_t (stick) |
| **Battery Level** | voltage_mv, prev_level | level_enum (with hysteresis) |
| **Calibration Math**  | raw_samples[N][6] | offsets[6], variance_ok |
| **Motor Mixer** | throttle, pitch, roll, yaw | dshot[4] (uint16, clamped) |
| **Attitude Estimator**| accel[3], gyro[3], dt | pitch, roll, yaw (float) |
| **Altitude Estimator**| baro_pa, tof_mm, dt | altitude_cm (int32) |
| **Position Estimator**| flow_dx, flow_dy, alt, dt | vel_x, vel_y (float) |
| **DSHOT Encoder** | throttle (uint16), telem_req | dshot_frame (uint16) |
| **Pre-flight Check**  | sensor_status, batt, link, sticks | pass/fail + reason |

### 2.2 Effectful Shell Modules

| Module | Side Effects |
|---|---|
| **CRSF Backend** | UART1 RX DMA → raw bytes → CRSF parser → drone_cmd_t |
| **BLE Backend** | UART2 RX/TX → BLE protocol parser → drone_cmd_t / telemetry |
| **SPI IMU Driver** | SPI1 DMA read ICM-42688 registers |
| **SPI Flash Driver** | SPI2 read/write/erase W25Q128 |
| **SPI OF Driver** | SPI2 read PMW3901 motion data |
| **I2C Baro Driver** | I2C1 read BMP390 pressure/temperature |
| **I2C ToF Driver** | I2C1 configure/read VL53L5CX |
| **ADC Battery HAL** | ADC1 DMA read battery voltage |
| **ADC Current HAL** | ADC2 read motor current via op-amp |
| **DSHOT DMA HAL** | TIM1 DMA output DSHOT frames to 4 motors  |
| **WS2812B DMA HAL** | SPI/TIM DMA output LED data |
| **GPIO HAL** | Buzzer PWM, button read |
| **USB CDC/DFU** | USB peripheral for serial/firmware update |
| **Blackbox Logger** | Collect pure core outputs → write to flash |
| **Watchdog HAL** | Refresh IWDG timer |
| **Main Loop** | Orchestrates shell ↔ core data flow |

### 2.3 Boundary Rules

1. Pure core modules MUST NOT include any Zephyr API calls (no `k_*`, no device bindings)
2. Pure core modules accept C primitive types and structs, never device pointers
3. All hardware interaction flows through the effectful shell
4. The shell calls pure core functions and acts on the returned action_list
5. Pure core modules are compilable and testable on the host (x86) without Zephyr
6. Pure core modules MUST NOT allocate heap memory (all static or stack)
7. Pure core modules MUST be reentrant (no static mutable state except PID integrators, which are passed as struct pointers)

---

## 3. Verification Tooling

| Tool | Target | Purpose |
|---|---|---|
| **TLA+** | State machine model | Prove safety & liveness of mode transitions, motor invariants, failsafe |
| **CBMC** | C source (pure core) | Bounded model checking: overflow, array bounds, termination |
| **Ztest**| Full firmware on target | Zephyr-native unit and integration tests |
| **Ztest (native_sim)** | Pure core on host | Fast iteration without hardware |
| **Fuzz** | CRSF + BLE parsers | libFuzzer / AFL++ on parsers in isolation |
| **HIL**  | Full system on hardware | Hardware-in-the-loop flight simulation |

### 3.1 TLA+ Scope

Model the state machine covering:
- States: {Calibrate, Diag, Running, Error}
- Events: {calib_ok, calib_fail, calib_timeout, arm, disarm,
           elrs_failsafe, low_batt_critical, low_batt_cutoff, imu_failure,
           excessive_tilt, motor_stall, motor_overcurrent, sw1_press,
           recalibrate, pre_flight_fail}
- Properties: VP-01 through VP-05, VP-12 through VP-17, VP-32

### 3.2 CBMC Scope

Bounded model check the following C functions:

| Function | Properties Checked |
|---|---|
| crsf_parse() | VP-18, VP-19, VP-20, VP-21 |
| ble_protocol_parse() | VP-22, VP-23, VP-24 |
| pid_rate_update() | VP-06, VP-09 |
| pid_angle_update() | VP-07, VP-09 |
| input_map_channels() | VP-10, VP-30 |
| motor_mixer_update() | VP-08, VP-28, VP-29 |
| adc_to_mv() | VP-11 |
| battery_level_update()  | VP-25 |
| calibration_compute() | VP-26 |
| arm_debounce_check() | VP-27 |
| dshot_encode() | VP-33 |
| attitude_update() | VP-34 |
| altitude_fuse() | VP-31 |
| pre_flight_check() | VP-32 |

### 3.3 Fuzz Testing Scope

| Target | Input | Properties Verified |
|---|---|---|
| CRSF parser | Arbitrary byte sequences | VP-18, VP-19, VP-21 |
| BLE protocol parser | Arbitrary byte sequences | VP-22, VP-23, VP-24 |
| Input mapper | Random channel values | VP-10, VP-30 |

Build parsers as standalone libraries (pure core) and link with libFuzzer.
Fuzz corpus seeded with valid CRSF and BLE frames, then mutated.

### 3.4 Hardware-in-the-Loop (HIL) Testing

| Test | Setup | Validates |
|---|---|---|
| IMU → PID → Motor loop | IMU on vibration table | VT-10, VT-11 (timing) |
| ELRS end-to-end | TX + RX in RF shielded box | VT-07 (link timing) |
| Failsafe | TX power off during armed | VP-17 (500 ms detect) |
| Battery simulation | Programmable power supply | VP-05, VP-25 |
| Motor current | Resistive motor load | VT-20 (accuracy) |
| Full flight sim | Drone on tethered rig | VT-18, VT-19 |

---

## 4. Traceability Matrix

| Spec (behavioral.md) | Verification Property | Test Type |
|---|---|---|
| INV-1 (motors off) | VP-02 | TLA+ proof |
| INV-2 (battery sampling) | VT-14 | Ztest timing |
| INV-3 (cutoff) | VP-05 | TLA+ proof |
| INV-4 (IMU failure) | VP-04 | TLA+ proof |
| INV-5 (watchdog) | VP-16 | TLA+ proof |
| INV-6 (PID windup) | VP-06, VP-07 | CBMC proof |
| INV-7 (max DSHOT) | VP-08 | CBMC proof |
| INV-8 (motor current limit)  | VP-12 | TLA+ proof |
| INV-9 (CRSF failsafe) | VP-17 | TLA+ proof |
| INV-10 (blackbox non-blocking)| VT-15 | Ztest+HW |
| EC-01 (CRSF CRC bad) | VP-20 | CBMC + Fuzz |
| EC-02 (CRSF too short) | VP-19 | Fuzz |
| EC-03 (CRSF sync wrong) | VP-18 | Fuzz |
| EC-04 (ELRS link lost) | VP-17 | TLA+ proof |
| EC-05 (ELRS link restored) | VP-01 | TLA+ proof |
| EC-10 (rapid arm/disarm) | VP-27 | CBMC |
| EC-11 (BLE checksum bad) | VP-23 | CBMC + Fuzz |
| EC-12 (IMU wrong ID) | VT-01 | Ztest |
| EC-13 (SPI bus error) | VT-05 | Ztest+HW |
| EC-16 (calibration moving) | VP-26 | CBMC |
| EC-17 (IMU failure Running)  | VP-04 | TLA+ proof |
| EC-18 (baro fail flight) | VP-01 | TLA+ proof |
| EC-22 (critical battery) | VP-05 | TLA+ proof |
| EC-25 (ADC hysteresis) | VP-25 | CBMC |
| EC-31 (throttle spike) | VP-08 | CBMC |
| EC-33 (excessive tilt) | VP-02 | TLA+ proof |
| EC-34 (motor stall) | VP-12 | TLA+ proof |
| EC-35 (motor overcurrent) | VP-12 | TLA+ proof |
| EC-38 (arm invalid calib) | VP-03, VP-32 | TLA+ proof |
| EC-39 (arm low batt) | VP-32 | TLA+ proof |
| EC-40 (arm no ELRS) | VP-32 | TLA+ proof |
| EC-41 (arm throttle high) | VP-32 | TLA+ proof |
| EC-42 (arm tilted) | VP-32 | TLA+ proof |
| EC-45 (boot low batt) | VP-05 | TLA+ proof |
| EC-47 (flash full) | VT-15 | Ztest |
| Mixer output clamping | VP-28, VP-29 | CBMC |
| Channel mapping bounds | VP-30 | CBMC |
| DSHOT encoding | VP-33 | CBMC |
| Attitude filter bounded | VP-34 | CBMC |
| Altitude fusion crossfade | VP-31 | CBMC |
| Pre-flight check completeness| VP-32 | TLA+ proof |

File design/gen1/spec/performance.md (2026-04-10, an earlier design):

# Performance Specification

## Flight Performance (Target)

| Parameter | Target Value | Notes |
|---|---|---|
| Flight Time | TBD | Depends on AUW and motor efficiency |
| Max Payload | TBD | Beyond self-weight |
| PID Tilt Limit | 45 deg | PID output saturates; no further tilt commanded |
| Emergency Tilt Cutoff  | 60 deg | Motors off immediately; transition to Diag |
| Max Altitude | Indoor use only | No barometer |

## Control Loop

| Parameter | Target Value | Notes |
|---|---|---|
| IMU Sample Rate | 1000 Hz | MPU6050 max rate |
| PID Loop Rate | 500 Hz | 2 ms period |
| PWM Frequency | 20 kHz | Above audible range |
| PWM Resolution | ~11.8 bits (3600 steps) | 72 MHz / 20 kHz; MAX_THROTTLE = 3599 |
| Bluetooth Command Rate | 50 Hz | 20 ms update interval |

## Response Time

| Event | Max Latency |
|---|---|
| IMU read to PID output | < 1 ms |
| Bluetooth command to action | < 20 ms |
| IMU failure detection | 50 ms (no valid data timeout) |
| Failsafe ramp-down complete  | 200 ms from detection |
| Battery ADC update | 100 ms |

## Power Budget (Estimated)

| Component | Current (mA) | Voltage | Power (mW) |
|---|---|---|---|
| STM32F103 @ 72MHz | 40 | 3.3V | 132 |
| MPU6050 | 4 | 3.3V | 13 |
| HM-13 Bluetooth | 30 | 3.3V | 99 |
| 4x Status LEDs | 20 | 3.3V | 66 |
| **Digital subtotal** | **94** | **3.3V** | **310** |
| 4x Motors (hover)  | TBD | 7.4V | TBD |
| **Total** | **TBD** | | **TBD** |

## Regulator Thermal

| Parameter | Value |
|---|---|
| Input Voltage | 7.4V (nominal) |
| Output Voltage | 3.3V |
| Dropout | 4.1V |
| Load Current (digital) | ~94 mA |
| Power Dissipation | ~385 mW |
| Thermal Resistance (SOT-223) | ~50 C/W (to PCB) |
| Temperature Rise | ~19 C |

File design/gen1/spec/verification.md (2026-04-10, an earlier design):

# Verification Architecture (VSDD Phase 1b)

## 1. Provable Properties Catalog

Properties are classified as **formally provable** (P) or **test-only** (T) based
on whether the logic is deterministic and side-effect-free.

### 1.1 Safety Properties (Must Prove)

| ID | Property | Class | Tool |
|---|---|---|---|
| VP-01 | State machine never reaches an undefined state | P | TLA+ |
| VP-02 | Motors PWM = 0 in any state other than Running/armed  | P | TLA+ |
| VP-03 | Calibrate → Diag only on success; never Calibrate → Running | P | TLA+ |
| VP-04 | Disarm from Running always reaches Diag within finite steps | P | TLA+ |
| VP-05 | Battery cutoff (< 6.0V) forces motors off in all states | P  | TLA+ |
| VP-06 | PID integrator absolute value <= WINDUP_MAX at all times | P | CBMC  |
| VP-07 | Motor PWM duty <= MAX_THROTTLE for all inputs | P | CBMC |
| VP-08 | No arithmetic overflow in PID calculation (int16 inputs, float intermediates) | P | CBMC |
| VP-09 | Joystick center (512,512) produces exactly zero setpoint | P | CBMC |
| VP-10 | Voltage divider ADC-to-mV conversion never overflows uint16 | P | CBMC |

### 1.2 Liveness Properties (Must Prove)

| ID | Property | Class | Tool |
|---|---|---|---|
| VP-11 | System always eventually exits Calibrate (success or timeout) | P | TLA+ |
| VP-12 | Motor ramp-down completes within duration_ms | P | TLA+ |
| VP-13 | Watchdog is refreshed at least once per PID period | P | TLA+ |

### 1.3 Protocol Properties (Must Prove)

| ID | Property | Class | Tool |
|---|---|---|---|
| VP-14 | Parser always terminates (no infinite loop on any input) | P  | CBMC |
| VP-15 | Parser output is empty OR has both valid id and value | P | CBMC |
| VP-16 | Parser discards any byte sequence that lacks SOH prefix | P  | CBMC |
| VP-17 | Parser buffer never reads/writes out of bounds | P | CBMC |

### 1.4 Additional Provable Properties (Reclassified from Test-Only)

| ID | Property | Class | Tool |
|---|---|---|---|
| VP-18 | Battery level hysteresis: warning at 7.0V, exit at 7.2V; critical at 6.6V, exit at 6.8V | P | CBMC |
| VP-19 | Calibration variance check rejects samples with stddev > threshold | P | CBMC |
| VP-20 | Arm debounce rejects re-arm when elapsed_ms < 1000 (timestamp is pure input) | P | CBMC |
| VP-21 | Motor mixer output clamped to [0, MAX_THROTTLE] for all inputs | P | CBMC |
| VP-22 | Motor mixer never produces negative duty values | P | CBMC |
| VP-23 | Slider-to-gain mapping stays within defined ranges (Kp: 0-5, Ki: 0-2, Kd: 0-1) | P | CBMC |

### 1.5 Testable-Only Properties

| ID | Property | Class | Tool |
|---|---|---|---|
| VT-01 | IMU WHO_AM_I returns 0x68 on valid hardware | T | Ztest |
| VT-02 | I2C bus recovery succeeds after SDA stuck low | T | Ztest+HW |
| VT-03 | Bluetooth disconnect detected within 500 ms | T | Ztest |
| VT-04 | LED patterns match mode (visual / GPIO check) | T | Ztest |
| VT-05 | PID loop timing meets 500 Hz +/- 5% on target HW | T | Ztest+HW |
| VT-06 | Motor test pulse duration is 500 ms +/- 10% | T | Ztest+HW |
| VT-07 | Telemetry messages arrive at specified rates | T | Ztest |

---

## 2. Purity Boundary Map

The architecture is split into a **deterministic pure core** (formally verifiable)
and an **effectful shell** (tested only).

```
+------------------------------------------------------------------+
|                        Effectful Shell                            |
|                                                                  |
|  +------------------+  +---------------+  +------------------+   |
|  | Input Backend    |  | I2C Driver    |  | GPIO / PWM HAL   |   |
|  | (MicroBlue, RC,  |  | (MPU6050)     |  | (Motors, LEDs)   |   |
|  |  USB, etc.)      |  |               |  |                  |   |
|  +--------+---------+  +-------+-------+  +--------+---------+   |
|           |                     |                   |             |
|           v                     v                   v             |
|  +--------+---------+  +-------+-------+  +--------+---------+   |
|  | Backend Parser   |  | IMU Reader    |  | Motor Writer     |   |
|  | (transport →     |  | (effectful)   |  | (effectful)      |   |
|  |  drone_cmd_t)    |  |               |  |                  |   |
|  +--------+---------+  +-------+-------+  +--------+---------+   |
|           |                     |                   ^             |
+-----------+---------------------+-------------------+-------------+
            |                     |                   |
            v                     v                   |
+------------------------------------------------------------------+
|                        Pure Core                                 |
|                                                                  |
|  +------------------+  +---------------+  +------------------+   |
|  | Command Dispatch |  | PID Controller|  | State Machine    |   |
|  | (drone_cmd_t,    |  | (setpoint,    |  | (event,state →   |   |
|  |  mode → event)   |  |  measured,dt  |  |  next_state,     |   |
|  |                  |  |  → output)    |  |  actions[])      |   |
|  +------------------+  +---------------+  +------------------+   |
|                                                                  |
|  +------------------+  +---------------+  +------------------+   |
|  | Input Mapper     |  | Battery Level |  | Calibration Math |   |
|  | (joystick raw →  |  | (mV → enum   |  | (samples[] →     |   |
|  |  setpoints)      |  |  w/ hysteresis)|  |  offsets[])      |   |
|  +------------------+  +---------------+  +------------------+   |
|                                                                  |
|  +------------------+  +------------------+                      |
|  | Motor Mixer      |  | Gain Mapper      |                      |
|  | (throttle,PID →  |  | (value 0-100 →   |                      |
|  |  duty[4])        |  |  float gain)     |                      |
|  +------------------+  +------------------+                      |
|                                                                  |
+------------------------------------------------------------------+
```

Note: Protocol-specific parsers (MicroBlue, etc.) sit in the effectful shell.
They translate transport bytes into `drone_cmd_t` (defined in `command.h`).
The pure core only sees `drone_cmd_t` — it never touches raw bytes or I/O.

### 2.1 Pure Core Modules

These modules are deterministic, take inputs, return outputs, and have no
side effects. They are the primary targets for formal verification and
property-based testing.

| Module | Inputs | Outputs |
|---|---|---|
| **State Machine** | current_state, event | next_state, action_list |
| **Command Dispatch**| drone_cmd_t, current_mode | drone_event_t or IGNORE |
| **PID Controller**  | setpoint, measured, dt, gains | control_output (float) |
| **Input Mapper** | joystick x, y (int16) | signed setpoint (-512..+511) |
| **Battery Level** | voltage_mv, prev_level | level_enum (with hysteresis) |
| **Calibration Math**| raw_samples[N][6] | offsets[6], variance_ok (bool) |
| **Motor Mixer** | throttle, pitch, roll, yaw | duty[4] (uint16, clamped) |
| **Gain Mapper** | value (uint8, 0-100) | gain (float, bounded) |

### 2.2 Effectful Shell Modules

These modules perform I/O and are tested via integration tests on target hardware.

| Module | Side Effects |
|---|---|
| **Input Backend** | Read from transport (UART, SPI, USB, etc); convert to drone_cmd_t |
| **MicroBlue Backend** | Input backend: UART → mb_parse → drone_cmd_t |
| **Telemetry Backend** | Serialize telemetry structs to transport format |
| **I2C Driver** | Read/write registers on MPU6050 |
| **PWM HAL** | Set timer compare registers for motors |
| **GPIO HAL** | Set LED pin states |
| **ADC HAL** | Read battery voltage analog input |
| **Watchdog HAL** | Refresh hardware watchdog timer |
| **Main Loop** | Orchestrates shell ↔ core data flow |

### 2.3 Boundary Rules

1. Pure core modules MUST NOT include any Zephyr API calls (no `k_*`, no device bindings)
2. Pure core modules accept C primitive types and structs, never device pointers
3. All hardware interaction flows through the effectful shell
4. The shell calls pure core functions and acts on the returned action_list
5. Pure core modules are compilable and testable on the host (x86) without Zephyr

---

## 3. Verification Tooling

| Tool | Target | Purpose |
|---|---|---|
| **TLA+** | State machine model | Prove safety & liveness of mode transitions, motor invariants |
| **CBMC** | C source (pure core) | Bounded model checking: overflow, array bounds, termination |
| **Ztest**| Full firmware on target | Zephyr-native unit and integration tests |
| **Ztest (native_sim)** | Pure core on host | Fast iteration without hardware |
| **Fuzz** | MicroBlue parser | libFuzzer / AFL++ on parser in isolation |

### 3.1 TLA+ Scope

Model the state machine as a TLA+ specification covering:
- States: {Calibrate, Diag, Running}
  - Note: Startup boot sequence is modeled as precondition to Calibrate.
    IMU failure at boot causes watchdog reset (no stable Error state in firmware).
- Events: {calib_ok, calib_fail, calib_timeout, arm, disarm,
           bt_disconnect, low_batt_critical, low_batt_cutoff, imu_failure,
           excessive_tilt, sw2_press, recalibrate}
- Properties to check: VP-01 through VP-05, VP-11 through VP-13

### 3.2 CBMC Scope

Bounded model check the following C functions:
- `microblue_parse()` — VP-14 through VP-17
- `pid_update()` — VP-06, VP-08
- `input_map_joystick()` — VP-09
- `motor_set_pwm()` — VP-07
- `adc_to_mv()` — VP-10

CBMC harnesses will use `__CPROVER_assume()` for preconditions and
`__CPROVER_assert()` for postconditions on all inputs within type range.

### 3.3 Fuzz Testing Scope

The MicroBlue parser is the primary external input boundary.
Fuzz with arbitrary byte sequences to verify:
- No buffer overflows (VP-17)
- Always terminates (VP-14)
- Output is well-formed or empty (VP-15)

Build parser as a standalone library (pure core) and link with libFuzzer.

---

## 4. Traceability Matrix

Every spec requirement traces to a verification property and test.

| Spec (behavioral.md) | Verification Property | Test Type |
|---|---|---|
| INV-1 (motors off) | VP-02 | TLA+ proof |
| INV-2 (battery sampling) | VT-07 | Ztest timing  |
| INV-3 (cutoff) | VP-05 | TLA+ proof |
| INV-4 (IMU failure) | VP-04 | TLA+ proof |
| INV-5 (watchdog) | VP-13 | TLA+ proof |
| INV-6 (PID windup) | VP-06 | CBMC proof |
| INV-7 (max throttle) | VP-07 | CBMC proof |
| EC-01 (malformed packet) | VP-14, VP-16 | Fuzz |
| EC-02 (partial packet) | VP-15 | Fuzz |
| EC-05 (bad joystick value) | VP-09 | CBMC + Ztest  |
| EC-06 (BT disconnect) | VP-04 | TLA+ proof |
| EC-08 (rapid arm/disarm) | VT-10 | Ztest |
| EC-09 (buffer overflow) | VP-17 | Fuzz |
| EC-16 (calibration moving) | VT-09 | Ztest |
| EC-18 (critical battery) | VP-05 | TLA+ proof |
| EC-21 (ADC hysteresis) | VT-08 | Ztest |
| EC-26 (throttle ramp) | VP-07 | CBMC + Ztest  |
| EC-28 (excessive tilt) | VP-02 | TLA+ proof |
| EC-31 (arm invalid offsets) | VP-03 | TLA+ proof |
| EC-36 (calibration timeout)| VP-11 | TLA+ proof |
| EC-03 (unknown widget ID)  | VP-15 | Fuzz + CBMC |
| EC-04 (empty value) | VP-15 | CBMC |
| EC-07 (BT reconnect) | VP-01 | TLA+ proof |
| EC-10 (slider out of range)| VP-23 | CBMC |
| EC-13 (stale IMU data) | VT-03 | Ztest |
| EC-15 (calibration not level)| Accepted risk | — |
| EC-20 (battery recovery) | VP-18 | CBMC |
| EC-22 (battery disconnected)| Accepted risk | — (hardware)  |
| EC-24 (motor test held) | VT-06 | Ztest |
| EC-25 (multiple motor tests)| VP-01 | TLA+ proof |
| EC-29 (single motor failure)| Accepted risk | — (no current sensing) |
| EC-33 (power on low batt)  | VP-05 | TLA+ proof |
| EC-34 (SW2 press Running)  | VP-04 | TLA+ proof |
| Mixer output clamping | VP-21, VP-22 | CBMC |
| Gain mapping bounds | VP-23 | CBMC |

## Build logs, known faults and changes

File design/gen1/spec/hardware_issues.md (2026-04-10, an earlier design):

# Hardware Issues

Known hardware issues, circuit design mistakes, and improvement items
for the miniDrone Rev 1 PCB.

## Circuit Design Mistakes

### HW-01: Missing MOSFET Gate Pull-Down Resistors

| Field | Detail |
|---|---|
| Severity | BLOCKING |
| Components | Q1-Q4 (SI2302) |
| Problem  | No 100K pull-down resistors on MOSFET gates. During MCU reset or power-on glitches, gate pins float and motors may spin unexpectedly. |
| Fix | Add 100K pull-down resistors from each gate to GND. |
| Reference | safety.md: Motor Safety - Startup Behavior |

### HW-02: No Reverse Polarity Protection

| Field | Detail |
|---|---|
| Severity | High |
| Components | J1, J5 (battery connectors) |
| Problem  | Reversed battery connection will damage LM1117, MCU, and peripherals. |
| Fix | Add P-channel MOSFET or Schottky diode on battery input. |
| Reference | safety.md: Battery Protection |

### HW-03: No Over-Current / Short Circuit Protection

| Field | Detail |
|---|---|
| Severity | Medium |
| Components | Battery input path |
| Problem  | A motor short or wiring fault draws unlimited current from battery. Relies entirely on battery BMS. |
| Fix | Add polyfuse (resettable PTC) on battery input. |
| Reference | safety.md: Battery Protection |

### HW-04: Missing Input LC Filter on Battery

| Field | Detail |
|---|---|
| Severity | Medium |
| Components | Battery input |
| Problem  | Motor PWM switching noise couples back into power rail, affecting ADC readings and digital logic. |
| Fix | Add 10 uH inductor + 100 uF capacitor LC filter on battery input. |
| Reference | safety.md: EMI / Signal Integrity |

### HW-05: Missing Gate Resistors on MOSFETs

| Field | Detail |
|---|---|
| Severity | Low |
| Components | Q1-Q4 gates |
| Problem  | No series gate resistors causes high dI/dt switching transients, contributing to EMI. |
| Fix | Add 100 ohm series resistors on each MOSFET gate drive line. |
| Reference | safety.md: EMI / Signal Integrity |

### HW-06: No ESD Protection on External Interfaces

| Field | Detail |
|---|---|
| Severity | Low |
| Components | J2 (Bluetooth), J3 (programming), J8 (SWD) |
| Problem  | No TVS diodes on any external-facing connector. ESD events during handling or programming can damage MCU. |
| Fix | Add TVS diode arrays on UART TX/RX, SWD, and battery lines. |
| Reference | safety.md: ESD Protection |

### HW-07: KiCad DRC Violations

| Field | Detail |
|---|---|
| Severity | Medium |
| Problem  | 6 connection_width warnings, 2 courtyard overlap errors, 4 footprint mismatches, 4 starved thermal reliefs. |
| Fix | Widen traces to match net class; adjust component placement; update footprints; improve thermal relief geometry. |
| Reference | safety.md: Known DRC Issues |

## Power Sequence Issues

### HW-08: IMU Powers Up Before HM-13 Bluetooth Module

| Field | Detail |
|---|---|
| Severity | Medium |
| Components | MPU6050 (J4), HM-13 (J2) |
| Problem  | Both peripherals share the 3.3V rail and power on simultaneously. The IMU begins outputting data before the HM-13 has completed its own initialization. The HM-13 draws significant inrush current during startup, causing a voltage dip that can produce erratic IMU readings during the critical calibration window. |
| Observed | First ~50 IMU samples after power-on show high variance (axis variance up to 2M), requiring a firmware warm-up discard period. |
| Fix | Add a load switch or RC delay on the IMU 3.3V supply so it powers on after the HM-13 has settled (~200 ms). Alternatively, add separate LDOs for analog and digital domains. |

## Mechanical / Usability Issues

### HW-09: J11 Jumper (BOOT0) Difficult to Use

| Field | Detail |
|---|---|
| Severity | Medium |
| Components | J11 (BOOT0 jumper) |
| Problem  | Entering UART bootloader mode requires manually inserting/removing a jumper on J11. This is tedious during iterative development and risks bending pins or losing the jumper cap. |
| Fix | Replace J11 with a tactile push button (active-high with pull-down) or add a DTR/RTS-controlled auto-reset circuit (transistor toggling BOOT0 + NRST from the USB-UART adapter). |

### HW-10: No Power Off When Batteries Connected

| Field | Detail |
|---|---|
| Severity | High |
| Components | SW3 (power switch), J1, J5 |
| Problem  | The power switch SW3 does not fully disconnect the battery from the circuit, or the switch position is ambiguous. When batteries are plugged in, the system cannot be fully powered off, leading to continuous current draw and potential deep-discharge of the LiPo cells. |
| Fix | Verify SW3 DPDT wiring cuts both +BATT and GND paths. If the switch is correctly wired, consider adding a high-side P-FET power switch for clean cutoff with lower contact resistance. Add a power indicator LED downstream of SW3 to confirm on/off state. |

### HW-11: Total Weight Too Heavy (74g)

| Field | Detail |
|---|---|
| Severity | High |
| Components | Entire assembly |
| Problem  | Measured all-up weight is 74g. For the brushed coreless motors and propellers used, this is too heavy for stable hover and adequate flight time. Target should be under 50g. |
| Breakdown | See mechanical.md weight budget (TBD entries need actual measurements). |
| Fix | Reduce PCB size (remove unused breakout headers J9, J10). Use lighter battery (smaller capacity or single-cell with boost converter). Minimize connector weight (solder motors directly). Remove unnecessary headers (J6 placeholder, J7 expansion). Consider 4-layer PCB to reduce board area. |

## Power Architecture Issues

### HW-13: LM1117 Regulator Unnecessary — Use Battery Voltage Directly

| Field | Detail |
|---|---|
| Severity | Medium |
| Components | U2 (LM1117MP-3.3), battery pack |
| Problem  | The current design uses an LM1117 LDO to regulate 7.4V (2S) down to 3.3V. This wastes ~385 mW as heat (4.1V dropout × 94 mA), adds weight and board space, and introduces a single point of failure. The motors already run directly from +BATT; only the MCU, IMU, and BT module need 3.3V. |
| Proposal | Use a 2S (7.4V) or 3S (11.1V) LiPo battery to power motors directly, and replace the LM1117 with a small buck converter (e.g., TPS562200 or MP2359) for the 3.3V rail. Benefits: higher efficiency (~90% vs ~45%), less heat, supports wider battery voltage range, and enables 3S for more motor thrust without redesigning the digital rail. Alternatively, for minimum weight, use a single-cell LiPo (3.7V) with a buck-boost to 3.3V and drive motors directly from the cell. |

## EMI / Interference Issues

### HW-12: HM-13 and MPU6050 Placement Interference

| Field | Detail |
|---|---|
| Severity | Medium |
| Components | HM-13 (J2), MPU6050 (J4) |
| Problem  | The Bluetooth module and IMU are mounted in close proximity on the PCB. The HM-13 2.4 GHz RF transmission introduces high-frequency noise that couples into the IMU's analog front-end, potentially affecting accelerometer and gyroscope readings during active BT communication. |
| Observed | Possible correlation between BT telemetry bursts and IMU noise spikes (needs further characterization). |
| Fix | Increase physical separation between HM-13 and MPU6050. Add ground pour / shielding between the two modules. Add ferrite beads (100 ohm @ 100 MHz) on I2C lines to the IMU. In Rev 2, place IMU at board center and BT module at board edge with antenna facing outward. |

## Summary

| ID | Issue | Severity | Category  |
|---|---|---|---|
| HW-01 | Missing MOSFET gate pull-downs | BLOCKING | Circuit |
| HW-02 | No reverse polarity protection | High | Circuit |
| HW-03 | No over-current protection | Medium | Circuit |
| HW-04 | Missing battery input LC filter | Medium  | Circuit |
| HW-05 | Missing MOSFET gate resistors  | Low | Circuit |
| HW-06 | No ESD protection | Low | Circuit |
| HW-07 | KiCad DRC violations | Medium | Circuit |
| HW-08 | IMU/HM-13 power sequence | Medium | Power |
| HW-09 | BOOT0 jumper usability | Medium | Usability |
| HW-10 | Cannot power off with battery  | High | Usability |
| HW-11 | Total weight 74g (too heavy) | High | Mechanical|
| HW-12 | BT/IMU placement interference  | Medium | EMI |
| HW-13 | LDO inefficient, use battery direct | Medium | Power |

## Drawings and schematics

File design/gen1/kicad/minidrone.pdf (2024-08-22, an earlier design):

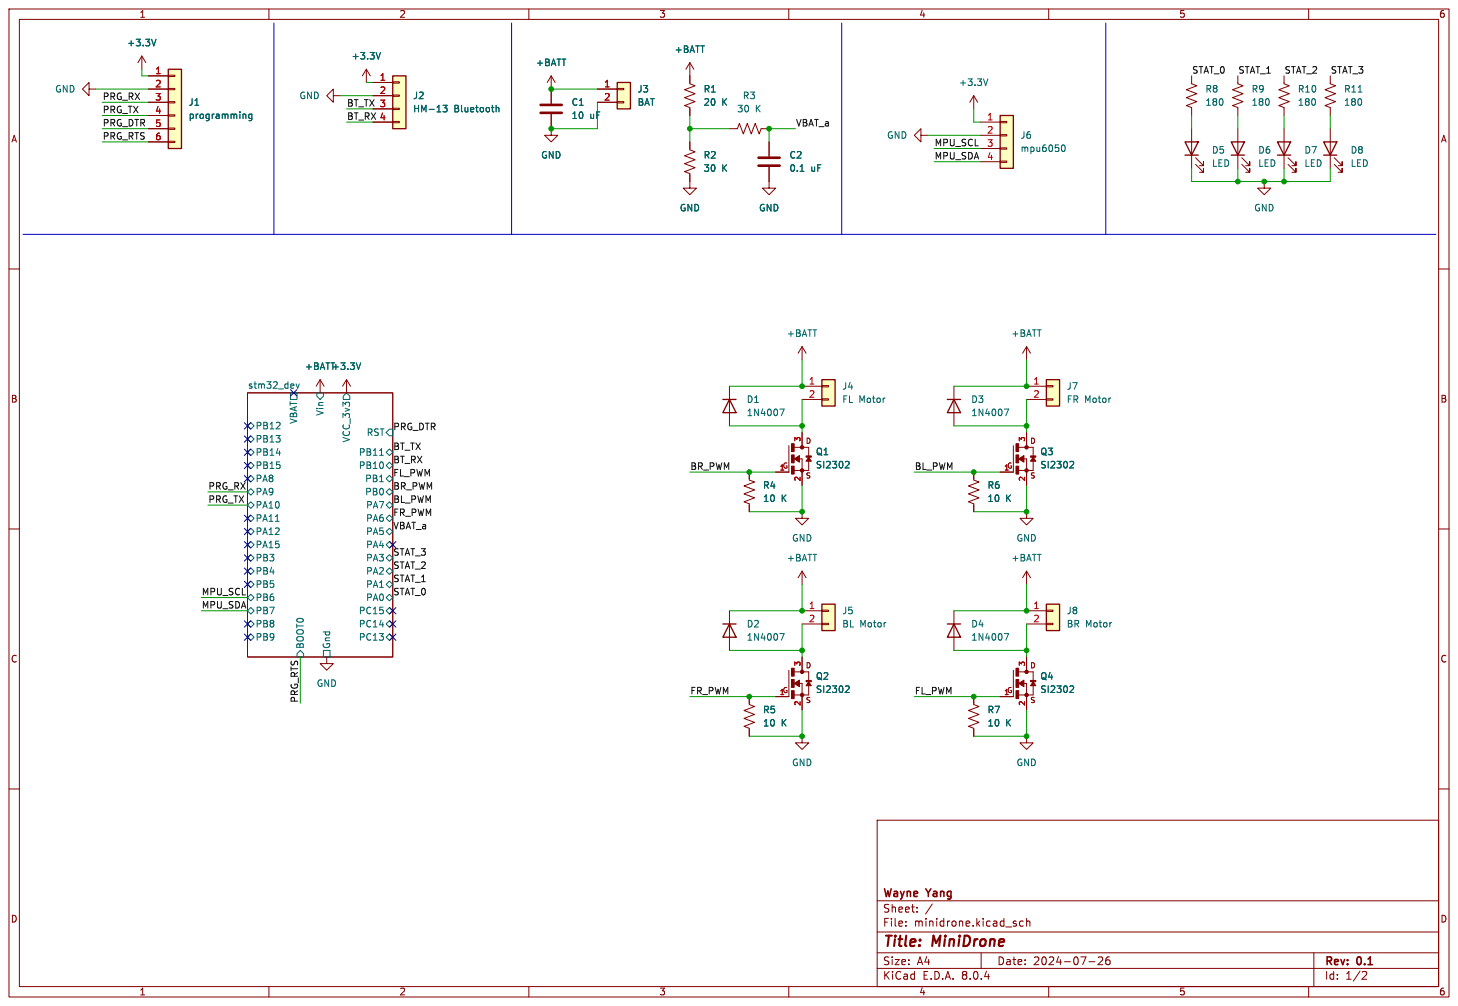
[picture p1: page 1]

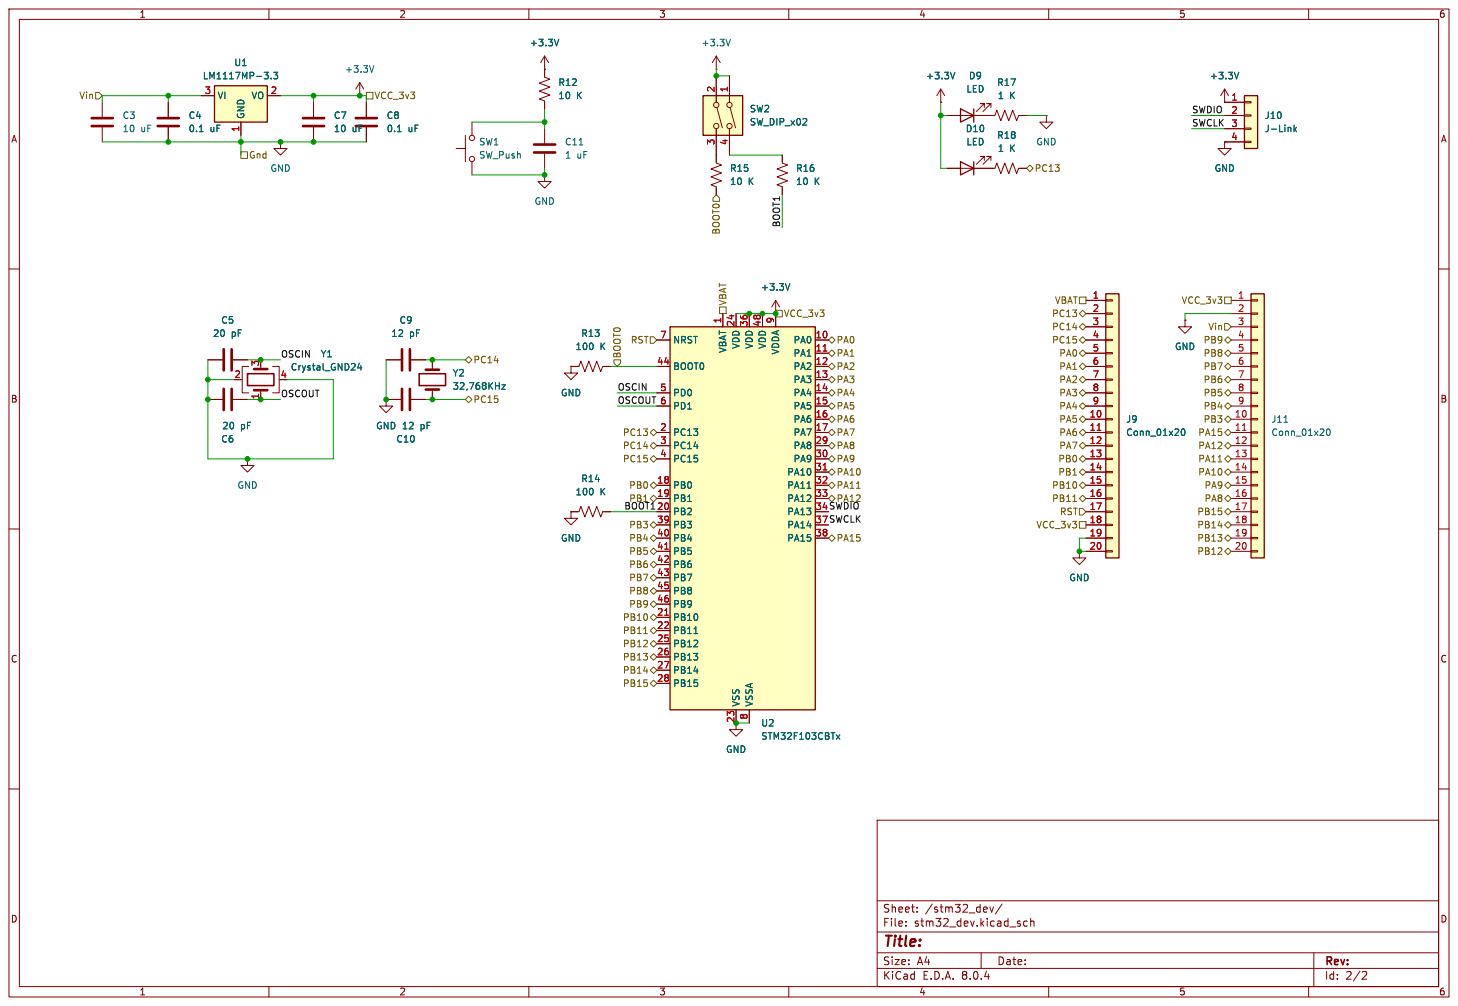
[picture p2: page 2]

1 PA0 10 PA1 11 PA2 12 PA3 13 PA4 14 PA5 15 PA6 16 PA7 17 PB0 18 PB1 19 PC13 2 PB2 20 PB10 21 PB11 22 VSS 23 VDD 24 PB12 25 PB13 26 PB14 27 PB15 28 PA8 29 PC14 3 PA9 30 PA10 31 PA11 32 PA12 33 PA13 34 VDD 36 PA14 37 PA15 38 PB3 39 PC15 4 PB4 40 PB5 41 PB6 42 PB7 43 BOOT0 44 PB8 45 PB9 46 VDD 48 PD0 5 PD1 6 NRST 7 VSSA

Id: 2/2 Title: File: stm32_dev.kicad_sch Sheet: /stm32_dev/

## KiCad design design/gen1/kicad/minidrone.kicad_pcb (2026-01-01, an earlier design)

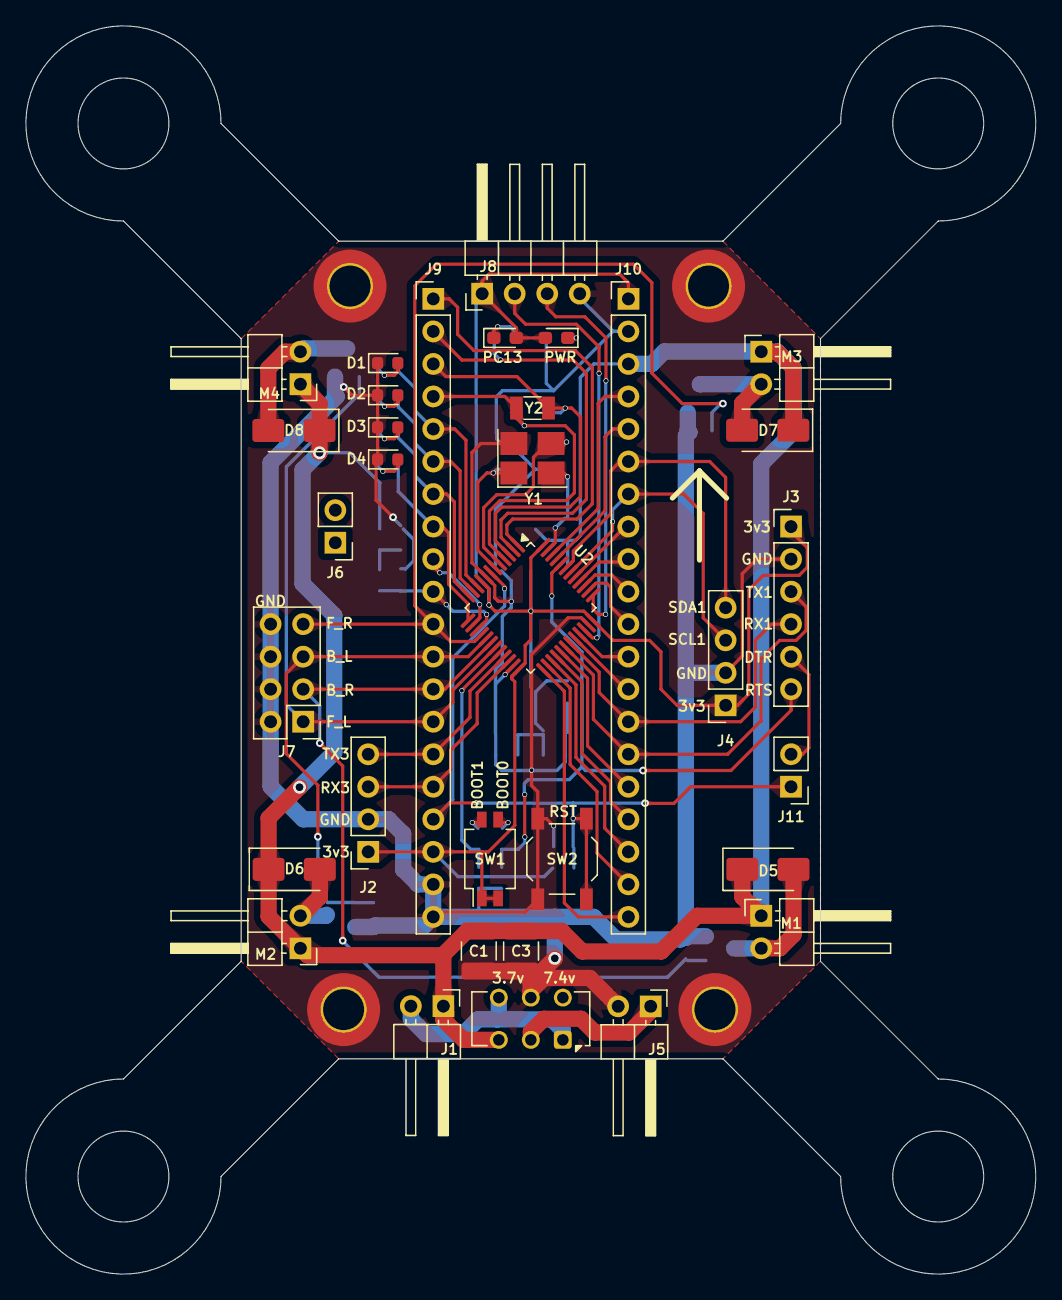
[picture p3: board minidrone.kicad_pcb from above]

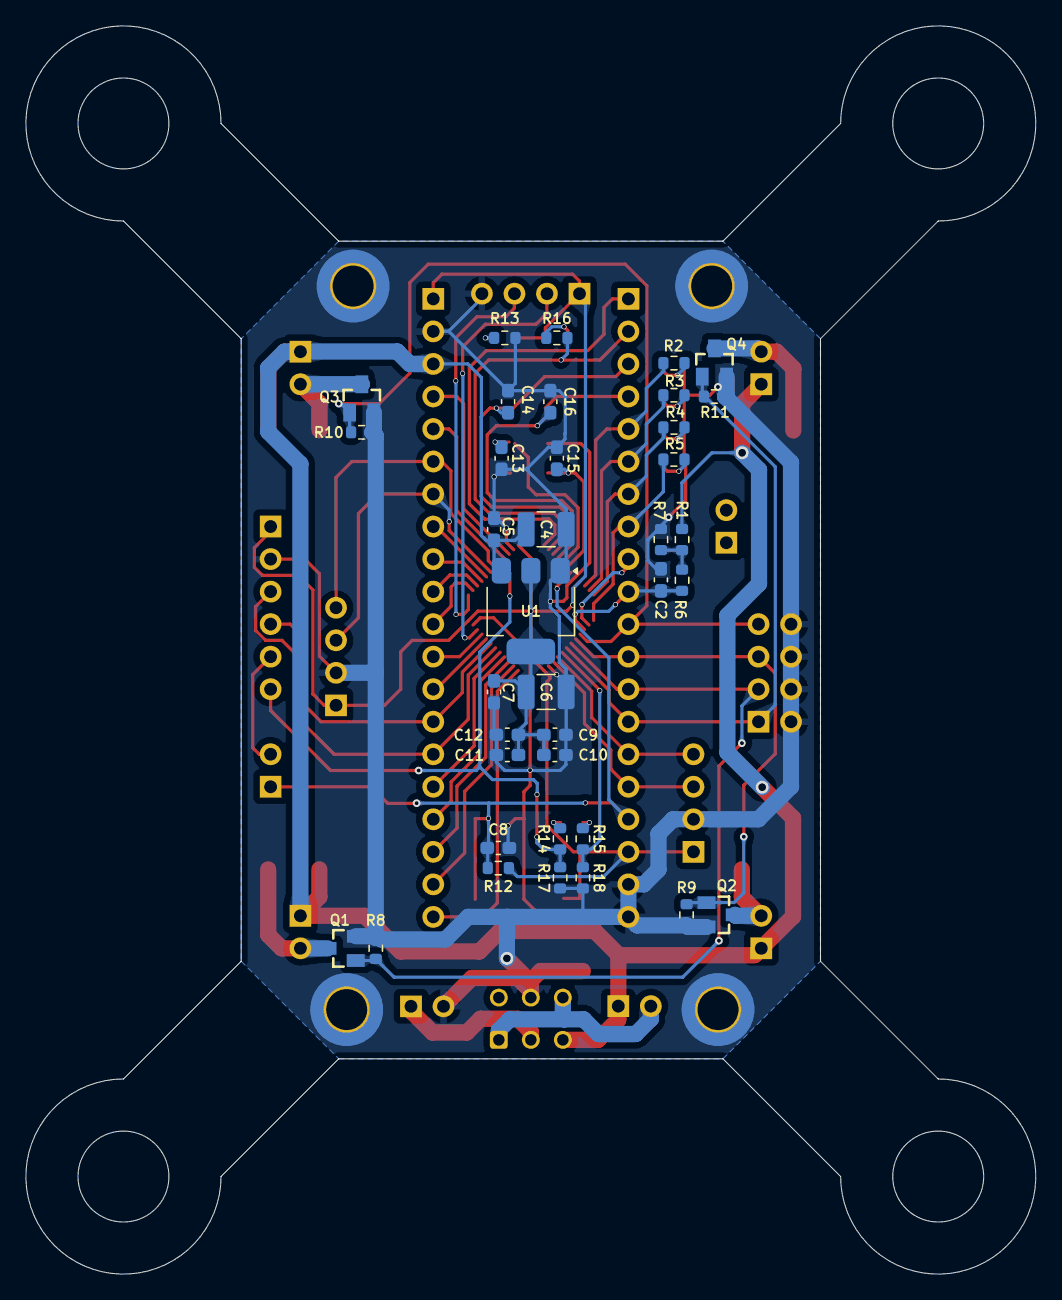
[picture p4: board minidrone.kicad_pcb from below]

Board: 2 copper layers, 78.9 x 97.5 mm, 74 parts (37 on the bottom side), 59 nets.

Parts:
C1, C3, C4, C6: 10 uF; C_1210_3225Metric_Pad1.33x2.70mm_HandSolder
C2, C5, C7, C9, C10, C11, C12: 0.1 uF; C_0603_1608Metric_Pad1.08x0.95mm_HandSolder
C8: 1 uF; C_0603_1608Metric_Pad1.08x0.95mm_HandSolder
C13, C15: 20 pF; C_0603_1608Metric_Pad1.08x0.95mm_HandSolder
C14, C16: 12 pF; C_0603_1608Metric_Pad1.08x0.95mm_HandSolder
D1, D2, D3, D4: LED; LED_0603_1608Metric
D5, D6, D7, D8: 1N4007; D_SMA
D9, D10: LED; LED_0603_1608Metric_Pad1.05x0.95mm_HandSolder
H1, H2, H3, H4: Pad; MountingHole_3.2mm_M3_ISO7380_Pad_TopBottom
J1, J5: BAT; PinHeader_1x02_P2.54mm_Horizontal
J2: HM-13 Bluetooth; PinSocket_1x04_P2.54mm_Vertical
J3: programming; PinHeader_1x06_P2.54mm_Vertical
J4: mpu6050; PinSocket_1x04_P2.54mm_Vertical
J6: place_holder; PinHeader_1x02_P2.54mm_Vertical
J7: Conn_02x04_Odd_Even; PinHeader_2x04_P2.54mm_Vertical
J8: J-Link; PinHeader_1x04_P2.54mm_Horizontal
J9, J10: Conn_01x20; PinHeader_1x20_P2.54mm_Vertical
J11: jumper; PinHeader_1x02_P2.54mm_Vertical
M1: BR; PinHeader_1x02_P2.54mm_Horizontal
M2: BL; PinHeader_1x02_P2.54mm_Horizontal
M3: FR; PinHeader_1x02_P2.54mm_Horizontal
M4: FL; PinHeader_1x02_P2.54mm_Horizontal
Q1, Q2, Q3, Q4: SI2302; SOT23
R1, R6: 30 K; R_0603_1608Metric
R2, R3, R4, R5: 180; R_0603_1608Metric
R7, R8, R9, R10, R11, R12, R14, R15: 10 K; R_0603_1608Metric
R13, R16: 1 K; R_0603_1608Metric
R17, R18: 100 K; R_0603_1608Metric
SW1: SW_DIP_x02; SW_DIP_SPSTx02_Slide_Omron_A6H-2101_W6.15mm_P1.27mm
SW2: SW_Push; SW_SPST_TL3342
SW3: V_sw; SW_CK_JS202011CQN_DPDT_Straight
U1: LM1117MP-3.3; SOT-223-3_TabPin2
U2: STM32F103CBTx; LQFP-48_7x7mm_P0.5mm
Y1: 8MHz; Crystal_SMD_3225-4Pin_3.2x2.5mm_HandSoldering
Y2: 32,768KHz; Crystal_SMD_3215-2Pin_3.2x1.5mm

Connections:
+3.3V: C6.1, C7.1, C9.1, C10.1, C11.1, C12.1, D9.2 (A), D10.2 (A), J2.1, J3.1, J4.1, J8.1, J9.18, J10.1, R12.1, SW1.1, SW1.2, U1.2 (VO), U2.9 (VDDA), U2.24 (VDD), U2.36 (VDD), U2.48 (VDD)
+BATT: C1.1, C3.1, C4.1, C5.1, D5.1 (K), D6.1 (K), D7.1 (K), D8.1 (K), J1.1, J10.3, M1.1 (+), M2.1 (+), M3.1 (+), M4.1 (+), R1.1, SW3.3 (C), U1.3 (VI)
/BL_PWM: J7.5, J9.12, Q2.1, R9.1, U2.17 (PA7)
/BR_PWM: J7.3, J9.13, Q1.1, R8.1, U2.18 (PB0)
/BT_RX: J2.4, J9.15, U2.21 (PB10)
/BT_TX: J2.3, J9.16, U2.22 (PB11)
/FL_PWM: J7.1, J9.14, Q4.1, R11.1, U2.19 (PB1)
/FR_PWM: J7.7, J9.11, Q3.1, R10.1, U2.16 (PA6)
/MPU_SCL: J4.3, J10.7, U2.42 (PB6)
/MPU_SDA: J4.4, J10.6, U2.43 (PB7)
/PRG_DTR: J3.5, J11.2
/PRG_RTS: J3.6, R14.1, R17.2, U2.44 (BOOT0)
/PRG_RX: J3.3, J10.15, U2.30 (PA9)
/PRG_TX: J3.4, J10.14, U2.31 (PA10)
/STAT_0: J9.5, R2.1, U2.10 (PA0)
/STAT_1: J9.6, R3.1, U2.11 (PA1)
/STAT_2: J9.7, R4.1, U2.12 (PA2)
/STAT_3: J9.8, R5.1, U2.13 (PA3)
/VBAT_a: C2.1, J9.10, R6.2, U2.15 (PA5)
/stm32_dev/BOOT1: R15.1, R18.2, U2.20 (PB2)
/stm32_dev/OSCIN: C13.2, U2.5 (PD0), Y1.3
/stm32_dev/OSCOUT: C15.1, U2.6 (PD1), Y1.1
/stm32_dev/PA4: J9.9, U2.14 (PA4)
/stm32_dev/PA8: J10.16, U2.29 (PA8)
/stm32_dev/PA11: J10.13, U2.32 (PA11)
/stm32_dev/PA12: J10.12, U2.33 (PA12)
/stm32_dev/PA15: J10.11, U2.38 (PA15)
/stm32_dev/PB3: J10.10, U2.39 (PB3)
/stm32_dev/PB4: J10.9, U2.40 (PB4)
/stm32_dev/PB5: J10.8, U2.41 (PB5)
/stm32_dev/PB8: J10.5, U2.45 (PB8)
/stm32_dev/PB9: J10.4, U2.46 (PB9)
/stm32_dev/PB12: J10.20, U2.25 (PB12)
/stm32_dev/PB13: J10.19, U2.26 (PB13)
/stm32_dev/PB14: J10.18, U2.27 (PB14)
/stm32_dev/PB15: J10.17, U2.28 (PB15)
/stm32_dev/PC13: J9.2, R16.2, U2.2 (PC13)
/stm32_dev/PC14: C14.2, J9.3, U2.3 (PC14), Y2.2
/stm32_dev/PC15: C16.1, J9.4, U2.4 (PC15), Y2.1
/stm32_dev/Reset: C8.1, J9.17, J11.1, R12.2, SW2.2, U2.7 (NRST)
/stm32_dev/SWCLK: J8.3, U2.37 (PA14)
/stm32_dev/SWDIO: J8.2, U2.34 (PA13)
/stm32_dev/VBAT: J9.1, U2.1 (VBAT)
GND: C1.2, C2.2, C3.2, C4.2, C5.2, C6.2, C7.2, C8.2, C9.2, C10.2, C11.2, C12.2, C13.1, C14.1, C15.2, C16.2, D1.1 (K), D2.1 (K), D3.1 (K), D4.1 (K), H1.1, H2.1, H3.1, H4.1, J2.2, J3.2, J4.2, J5.2, J7.2, J7.4, J7.6, J7.8, J8.4, J9.19, J9.20, J10.2, Q1.2, Q2.2, Q3.2, Q4.2, R7.2, R8.2, R9.2, R10.2, R11.2, R13.1, R17.1, R18.1, SW2.1, SW3.5 (B), U1.1 (GND), U2.8 (VSSA), U2.23 (VSS), U2.35 (VSS), U2.47 (VSS), Y1.2, Y1.4
unnamed: D1.2 (A), R2.2
unnamed: D2.2 (A), R3.2
unnamed: D3.2 (A), R4.2
unnamed: D4.2 (A), R5.2
unnamed: D5.2 (A), M1.2 (-), Q1.3
unnamed: D6.2 (A), M2.2 (-), Q2.3
unnamed: D7.2 (A), M3.2 (-), Q3.3
unnamed: D8.2 (A), M4.2 (-), Q4.3
unnamed: D9.1 (K), R13.2
unnamed: D10.1 (K), R16.1
unnamed: J1.2, SW3.1 (A), SW3.4 (A)
unnamed: J5.1, SW3.2 (B)
unnamed: R1.2, R6.1, R7.1
unnamed: R14.2, SW1.3
unnamed: R15.2, SW1.4

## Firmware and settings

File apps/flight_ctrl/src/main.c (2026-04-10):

/* SPDX-License-Identifier: Apache-2.0
 *
 * MiniDrone Flight Controller - Main Loop
 *
 * Orchestrates the effectful shell ↔ pure core data flow per the
 * behavioral spec startup sequence and mode state machine.
 */

#include <zephyr/kernel.h>
#include <zephyr/drivers/watchdog.h>
#include <zephyr/logging/log.h>

#include <app/shell.h>
#include <app/core/state_machine.h>
#include <app/core/pid.h>
#include <app/core/mixer.h>
#include <app/core/input_mapper.h>
#include <app/core/battery.h>
#include <app/core/calibration.h>
#include <app/core/command.h>

LOG_MODULE_REGISTER(main, LOG_LEVEL_INF);

#define PID_LOOP_PERIOD_MS 2    /* 500 Hz */
#define BATTERY_PERIOD_MS  200  /* 5 Hz */
#define TELEM_PERIOD_MS    100  /* 10 Hz */
#define BATT_TELEM_MS      1000 /* 1 Hz */
#define CALIB_SAMPLES      200
#define CALIB_TIMEOUT_MS   5000
#define IMU_TIMEOUT_MS     50
#define MOTOR_RAMP_MS      200
#define MOTOR_TEST_DUTY    1080 /* ~30% of MAX_THROTTLE */
#define MOTOR_TEST_MS      500

/* Debug: string tables for state machine logging */
static const char *mode_str[] = {
	[DRONE_MODE_CALIBRATE] = "CALIBRATE",
	[DRONE_MODE_DIAG]      = "DIAG",
	[DRONE_MODE_RUNNING]   = "RUNNING",
};

static const char *event_str[] = {
	[EVENT_CALIB_OK]         = "CALIB_OK",
	[EVENT_CALIB_FAIL]       = "CALIB_FAIL",
	[EVENT_CALIB_TIMEOUT]    = "CALIB_TIMEOUT",
	[EVENT_ARM]              = "ARM",
	[EVENT_DISARM]           = "DISARM",
	[EVENT_RECALIBRATE]      = "RECALIBRATE",
	[EVENT_BT_DISCONNECT]    = "BT_DISCONNECT",
	[EVENT_LOW_BATT_CRITICAL] = "LOW_BATT_CRITICAL",
	[EVENT_LOW_BATT_CUTOFF]  = "LOW_BATT_CUTOFF",
	[EVENT_IMU_FAILURE]      = "IMU_FAILURE",
	[EVENT_EXCESSIVE_TILT]   = "EXCESSIVE_TILT",
	[EVENT_SW2_PRESS]        = "SW2_PRESS",
};

static const char *action_str[] = {
	[ACTION_NONE]              = "NONE",
	[ACTION_MOTORS_OFF]        = "MOTORS_OFF",
	[ACTION_MOTORS_RAMP_DOWN]  = "MOTORS_RAMP_DOWN",
	[ACTION_PID_RESET]         = "PID_RESET",
	[ACTION_REPORT_CALIB_OK]   = "REPORT_CALIB_OK",
	[ACTION_REPORT_CALIB_FAIL] = "REPORT_CALIB_FAIL",
	[ACTION_REPORT_ERROR]      = "REPORT_ERROR",
	[ACTION_REPORT_MODE]       = "REPORT_MODE",
	[ACTION_REPORT_LOWBATT]    = "REPORT_LOWBATT",
};

static sm_result_t sm_process_logged(const sm_state_t *state,
				     drone_event_t event, uint32_t now_ms)
{
	sm_result_t r = sm_process(state, event, now_ms);

	LOG_INF("SM: %s + %s -> %s (actions:%d)",
		mode_str[state->mode], event_str[event],
		mode_str[r.next_mode], r.action_count);
	for (int i = 0; i < r.action_count; i++) {
		LOG_INF("  action[%d]: %s", i, action_str[r.actions[i]]);
	}
	return r;
}

/* State */
static sm_state_t sm_state;
static pid_state_t pid_pitch, pid_roll, pid_yaw;
static battery_level_t batt_level = BATT_NORMAL;

/* Joystick inputs (updated by BT commands) */
static int16_t throttle_input;
static int16_t yaw_input;
static int16_t pitch_input;
static int16_t roll_input;

/* Ramp-down state */
static bool ramp_active;
static int64_t ramp_start_ms;
static uint16_t ramp_start_duty[4];
static uint16_t last_duty[4];

/* Timers */
static int64_t last_pid_ms;
static int64_t last_batt_ms;
static int64_t last_telem_ms;
static int64_t last_batt_telem_ms;
static int64_t last_imu_ok_ms;

static void execute_actions(const sm_result_t *result)
{
	for (int i = 0; i < result->action_count; i++) {
		switch (result->actions[i]) {
		case ACTION_MOTORS_OFF:
			shell_motor_all_off();
			ramp_active = false;
			memset(last_duty, 0, sizeof(last_duty));
			break;
		case ACTION_MOTORS_RAMP_DOWN:
			ramp_active = true;
			ramp_start_ms = k_uptime_get();
			memcpy(ramp_start_duty, last_duty, sizeof(last_duty));
			break;
		case ACTION_PID_RESET:
			pid_reset(&pid_pitch);
			pid_reset(&pid_roll);
			pid_reset(&pid_yaw);
			throttle_input = 0;
			yaw_input = 0;
			pitch_input = 0;
			roll_input = 0;
			break;
		case ACTION_REPORT_CALIB_OK:
			shell_bt_send_calib(true);
			break;
		case ACTION_REPORT_CALIB_FAIL:
			shell_bt_send_calib(false);
			break;
		case ACTION_REPORT_ERROR:
			shell_bt_send_error("rejected");
			break;
		case ACTION_REPORT_MODE:
			shell_bt_send_mode(result->next_mode);
			break;
		case ACTION_REPORT_LOWBATT:
			shell_bt_send_lowbatt(batt_level);
			break;
		default:
			break;
		}
	}
}

static drone_event_t cmd_to_event(const drone_cmd_t *cmd)
{
	switch (cmd->type) {
	case CMD_ARM:
		return EVENT_ARM;
	case CMD_DISARM:
		return EVENT_DISARM;
	case CMD_CALIBRATE:
		return EVENT_RECALIBRATE;
	default:
		return -1; /* Not a state transition command */
	}
}

static void handle_command(const drone_cmd_t *cmd, uint32_t now_ms)
{
	switch (cmd->type) {
	case CMD_ARM:
	case CMD_DISARM:
	case CMD_CALIBRATE: {
		drone_event_t event = cmd_to_event(cmd);
		sm_result_t result = sm_process_logged(&sm_state, event, now_ms);

		execute_actions(&result);
		sm_apply(&sm_state, &result);
		break;
	}
	case CMD_JOYSTICK:
		if (sm_state.mode != DRONE_MODE_RUNNING) {
			break;
		}
		if (cmd->joystick.axis == 0) {
			throttle_input = cmd->joystick.y;
			yaw_input = cmd->joystick.x;
		} else {
			pitch_input = cmd->joystick.y;
			roll_input = cmd->joystick.x;
		}
		break;
	case CMD_SET_PID_GAIN:
		if (sm_state.mode != DRONE_MODE_RUNNING) {
			break;
		}
		float gain;

		switch (cmd->pid_gain.gain) {
		case GAIN_KP:
			gain = input_map_kp(cmd->pid_gain.value);
			pid_set_gains(&pid_pitch, gain, pid_pitch.ki,
				      pid_pitch.kd);
			pid_set_gains(&pid_roll, gain, pid_roll.ki,
				      pid_roll.kd);
			pid_set_gains(&pid_yaw, gain, pid_yaw.ki, pid_yaw.kd);
			break;
		case GAIN_KI:
			gain = input_map_ki(cmd->pid_gain.value);
			pid_set_gains(&pid_pitch, pid_pitch.kp, gain,
				      pid_pitch.kd);
			pid_set_gains(&pid_roll, pid_roll.kp, gain,
				      pid_roll.kd);
			pid_set_gains(&pid_yaw, pid_yaw.kp, gain, pid_yaw.kd);
			break;
		case GAIN_KD:
			gain = input_map_kd(cmd->pid_gain.value);
			pid_set_gains(&pid_pitch, pid_pitch.kp, pid_pitch.ki,
				      gain);
			pid_set_gains(&pid_roll, pid_roll.kp, pid_roll.ki,
				      gain);
			pid_set_gains(&pid_yaw, pid_yaw.kp, pid_yaw.ki, gain);
			break;
		}
		break;
	case CMD_MOTOR_TEST:
		if (sm_state.mode != DRONE_MODE_DIAG) {
			break;
		}
		if (cmd->motor_test.motor_id < 4) {
			uint16_t test_duty[4] = {0};

			test_duty[cmd->motor_test.motor_id] = MOTOR_TEST_DUTY;
			shell_motor_set(test_duty);
			k_msleep(MOTOR_TEST_MS);
			shell_motor_all_off();
		}
		break;
	default:
		break;
	}
}

static void run_calibration(void)
{
	LOG_INF("Starting IMU calibration...");
	shell_led_set(0, false); /* Will blink in main loop */

	/* Discard initial samples while MPU6050 settles after power-on */
	int16_t discard[6];

	for (int i = 0; i < 50; i++) {
		shell_imu_read(discard);
		k_msleep(5);
	}

	static int16_t samples[CALIB_SAMPLES][CALIB_AXES];
	int64_t start = k_uptime_get();

	for (int i = 0; i < CALIB_SAMPLES; i++) {
		if ((k_uptime_get() - start) > CALIB_TIMEOUT_MS) {
			sm_result_t r = sm_process_logged(&sm_state,
						   EVENT_CALIB_TIMEOUT,
						   (uint32_t)k_uptime_get());
			execute_actions(&r);
			sm_apply(&sm_state, &r);
			return;
		}

		int ret = shell_imu_read(samples[i]);

		if (ret < 0) {
			sm_result_t r = sm_process_logged(&sm_state, EVENT_CALIB_FAIL,
						   (uint32_t)k_uptime_get());
			execute_actions(&r);
			sm_apply(&sm_state, &r);
			return;
		}
		k_msleep(5);
	}

	/* Debug: log first few samples */
	LOG_INF("Sample[0]: [%d,%d,%d,%d,%d,%d]",
		samples[0][0], samples[0][1], samples[0][2],
		samples[0][3], samples[0][4], samples[0][5]);
	LOG_INF("Sample[99]: [%d,%d,%d,%d,%d,%d]",
		samples[99][0], samples[99][1], samples[99][2],
		samples[99][3], samples[99][4], samples[99][5]);
	LOG_INF("Sample[199]: [%d,%d,%d,%d,%d,%d]",
		samples[199][0], samples[199][1], samples[199][2],
		samples[199][3], samples[199][4], samples[199][5]);

	/* Debug: compute and log per-axis variance */
	for (int a = 0; a < CALIB_AXES; a++) {
		int64_t sum = 0;
		for (int i = 0; i < CALIB_SAMPLES; i++) {
			sum += samples[i][a];
		}
		int16_t mean = (int16_t)(sum / CALIB_SAMPLES);
		int64_t var_sum = 0;
		for (int i = 0; i < CALIB_SAMPLES; i++) {
			int32_t diff = samples[i][a] - mean;
			var_sum += (int64_t)diff * diff;
		}
		int64_t variance = var_sum / CALIB_SAMPLES;
		LOG_INF("Axis %d: mean=%d variance=%lld", a, mean,
			variance);
	}

	calib_result_t cr = calib_compute(samples, CALIB_SAMPLES);
	drone_event_t event = cr.ok ? EVENT_CALIB_OK : EVENT_CALIB_FAIL;
	sm_result_t r = sm_process_logged(&sm_state, event,
				   (uint32_t)k_uptime_get());

	execute_actions(&r);
	sm_apply(&sm_state, &r);

	if (cr.ok) {
		LOG_INF("Calibration OK: offsets [%d,%d,%d,%d,%d,%d]",
			cr.offsets[0], cr.offsets[1], cr.offsets[2],
			cr.offsets[3], cr.offsets[4], cr.offsets[5]);
	} else {
		LOG_WRN("Calibration failed: high variance (threshold=%d)",
			CALIB_VARIANCE_THRESHOLD);
	}
}

static void run_pid_loop(int64_t now_ms)
{
	float dt = (float)(now_ms - last_pid_ms) / 1000.0f;

	last_pid_ms = now_ms;

	/* Read IMU */
	int16_t imu_data[6];

	if (shell_imu_read(imu_data) < 0) {
		if ((now_ms - last_imu_ok_ms) > IMU_TIMEOUT_MS) {
			sm_result_t r = sm_process_logged(&sm_state,
						   EVENT_IMU_FAILURE,
						   (uint32_t)now_ms);
			execute_actions(&r);
			sm_apply(&sm_state, &r);
		}
		return;
	}
	last_imu_ok_ms = now_ms;

	/* Map throttle from signed input to [0, MAX_THROTTLE] */
	float thr = 0.0f;

	if (throttle_input > 0) {
		thr = (float)throttle_input * (float)MAX_THROTTLE / 512.0f;
	}

	/* PID update */
	float p_out = pid_update(&pid_pitch, (float)pitch_input,
				 (float)imu_data[0], dt);
	float r_out = pid_update(&pid_roll, (float)roll_input,
				 (float)imu_data[1], dt);
	float y_out = pid_update(&pid_yaw, (float)yaw_input,
				 (float)imu_data[5], dt);

	/* Mix and output */
	mixer_update(thr, p_out, r_out, y_out, last_duty);
	shell_motor_set(last_duty);
}

static void update_ramp(int64_t now_ms)
{
	if (!ramp_active) {
		return;
	}

	int64_t elapsed = now_ms - ramp_start_ms;

	if (elapsed >= MOTOR_RAMP_MS) {
		shell_motor_all_off();
		ramp_active = false;
		memset(last_duty, 0, sizeof(last_duty));
		return;
	}

	float factor = 1.0f - (float)elapsed / (float)MOTOR_RAMP_MS;
	uint16_t duty[4];

	for (int i = 0; i < 4; i++) {
		duty[i] = (uint16_t)((float)ramp_start_duty[i] * factor);
	}
	shell_motor_set(duty);
}

int main(void)
{
	LOG_INF("MiniDrone Flight Controller starting...");

	/* Step 2-6: Initialize all subsystems */
	int ret;

	ret = shell_led_init();
	if (ret < 0) {
		LOG_ERR("LED init failed: %d", ret);
	}

	shell_led_set(0, true); /* STAT_0 on during init */

	ret = shell_bt_init();
	if (ret < 0) {
		LOG_ERR("Bluetooth init failed: %d", ret);
	}

	ret = shell_motor_init();
	if (ret < 0) {
		LOG_ERR("Motor init failed: %d", ret);
	}
	shell_motor_all_off();

	ret = shell_battery_init();
	if (ret < 0) {
		LOG_ERR("Battery init failed: %d", ret);
	}

	/* Step 7: Verify IMU */
	ret = shell_imu_init();
	if (ret < 0) {
		LOG_ERR("IMU init failed: %d", ret);
		shell_bt_send_error("imu_init_fail");
		/* Watchdog will reset us */
		while (1) {
			shell_led_toggle(0);
			k_msleep(100);
		}
	}

	/* Initialize pure core state */
	sm_init(&sm_state);
	pid_init(&pid_pitch);
	pid_init(&pid_roll);
	pid_init(&pid_yaw);

	/* Set default PID gains */
	pid_set_gains(&pid_pitch, 1.0f, 0.1f, 0.05f);
	pid_set_gains(&pid_roll, 1.0f, 0.1f, 0.05f);
	pid_set_gains(&pid_yaw, 1.0f, 0.1f, 0.05f);

	int64_t now_ms = k_uptime_get();

	last_pid_ms = now_ms;
	last_batt_ms = now_ms;
	last_telem_ms = now_ms;
	last_batt_telem_ms = now_ms;
	last_imu_ok_ms = now_ms;

	/* Log initial battery reading */
	{
		uint16_t raw = shell_battery_read_raw();
		uint16_t mv = battery_adc_to_mv(raw);

		LOG_INF("Battery: raw=%u mv=%u", raw, mv);
	}

	LOG_INF("All systems initialized. Entering Calibrate mode.");

	/* Main loop */
	while (1) {
		now_ms = k_uptime_get();

		/* Poll BT commands */
		drone_cmd_t cmd = shell_bt_poll();

		if (cmd.type != CMD_NONE) {
			handle_command(&cmd, (uint32_t)now_ms);
		}

		/* Battery monitoring (5 Hz) */
		if ((now_ms - last_batt_ms) >= BATTERY_PERIOD_MS) {
			last_batt_ms = now_ms;
			uint16_t raw = shell_battery_read_raw();
			uint16_t mv = battery_adc_to_mv(raw);
			battery_level_t new_level = battery_level(mv,
								  batt_level);

			if (new_level != batt_level) {
				batt_level = new_level;
				if (batt_level == BATT_CUTOFF) {
					sm_result_t r = sm_process_logged(
						&sm_state,
						EVENT_LOW_BATT_CUTOFF,
						(uint32_t)now_ms);
					execute_actions(&r);
					sm_apply(&sm_state, &r);
				} else if (batt_level == BATT_CRITICAL) {
					sm_result_t r = sm_process_logged(
						&sm_state,
						EVENT_LOW_BATT_CRITICAL,
						(uint32_t)now_ms);
					execute_actions(&r);
					sm_apply(&sm_state, &r);
				}
				shell_led_set(2, batt_level >= BATT_WARNING);
			}

			/* Battery telemetry (1 Hz) */
			if ((now_ms - last_batt_telem_ms) >= BATT_TELEM_MS) {
				last_batt_telem_ms = now_ms;
				shell_bt_send_battery(mv);
			}
		}

		/* Mode-specific logic */
		switch (sm_state.mode) {
		case DRONE_MODE_CALIBRATE:
			run_calibration();
			break;

		case DRONE_MODE_DIAG:
			shell_led_set(0, true);
			shell_led_set(1, false);
			/* IMU telemetry (10 Hz) */
			if ((now_ms - last_telem_ms) >= TELEM_PERIOD_MS) {
				last_telem_ms = now_ms;
				int16_t imu_data[6];

				if (shell_imu_read(imu_data) == 0) {
					shell_bt_send_imu(imu_data);
				}
			}
			break;

		case DRONE_MODE_RUNNING:
			shell_led_set(0, true);
			shell_led_set(1, true);
			if (ramp_active) {
				update_ramp(now_ms);
			} else if ((now_ms - last_pid_ms) >= PID_LOOP_PERIOD_MS) {
				run_pid_loop(now_ms);
			}
			break;
		}

		k_msleep(1);
	}

	return 0;
}

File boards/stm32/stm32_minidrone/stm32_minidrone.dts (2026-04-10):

/*
 * SPDX-License-Identifier: Apache-2.0
 *
 * STM32 MiniDrone Board Device Tree
 *
 * Pin mapping (from KiCad schematic):
 *   PA0-PA3  : STAT_0..STAT_3 (GPIO LEDs)
 *   PA5      : VBAT_a (ADC1_IN5, battery voltage)
 *   PA6      : FR_PWM (TIM3_CH1)
 *   PA7      : BL_PWM (TIM3_CH2)
 *   PA9/PA10 : USART1 (debug console)
 *   PB0      : BR_PWM (TIM3_CH3)
 *   PB1      : FL_PWM (TIM3_CH4)
 *   PB6/PB7  : I2C1 (MPU6050)
 *   PB10/PB11: USART3 (HM-13 Bluetooth)
 *   PC13     : PWR LED
 */

/dts-v1/;
#include <st/f1/stm32f103Xb.dtsi>
#include <st/f1/stm32f103r(8-b)tx-pinctrl.dtsi>

/ {
	model = "STM32 minidrone Board";
	compatible = "st,stm32f103cb";

	chosen {
		zephyr,console = &usart1;
		zephyr,shell-uart = &usart1;
		zephyr,sram = &sram0;
		zephyr,flash = &flash0;
	};

	leds {
		compatible = "gpio-leds";

		pwr_led: pwr_led {
			gpios = <&gpioc 13 GPIO_ACTIVE_LOW>;
			label = "PWR";
		};

		stat0: stat_0 {
			gpios = <&gpioa 0 GPIO_ACTIVE_HIGH>;
			label = "STAT_0";
		};

		stat1: stat_1 {
			gpios = <&gpioa 1 GPIO_ACTIVE_HIGH>;
			label = "STAT_1";
		};

		stat2: stat_2 {
			gpios = <&gpioa 2 GPIO_ACTIVE_HIGH>;
			label = "STAT_2";
		};

		stat3: stat_3 {
			gpios = <&gpioa 3 GPIO_ACTIVE_HIGH>;
			label = "STAT_3";
		};
	};

	aliases {
		led0 = &pwr_led;
		stat0 = &stat0;
		stat1 = &stat1;
		stat2 = &stat2;
		stat3 = &stat3;
		bt-uart = &usart3;
	};
};

&clk_hse {
	clock-frequency = <DT_FREQ_M(8)>;
	status = "okay";
};

&pll {
	mul = <9>;
	clocks = <&clk_hse>;
	status = "okay";
};

&rcc {
	clocks = <&pll>;
	clock-frequency = <DT_FREQ_M(72)>;
	ahb-prescaler = <1>;
	apb1-prescaler = <2>;
	apb2-prescaler = <1>;
};

/* Debug console */
&usart1 {
	pinctrl-0 = <&usart1_tx_pa9 &usart1_rx_pa10>;
	pinctrl-names = "default";
	current-speed = <115200>;
	status = "okay";
};

/* Bluetooth HM-13 */
&usart3 {
	pinctrl-0 = <&usart3_tx_pb10 &usart3_rx_pb11>;
	pinctrl-names = "default";
	current-speed = <38400>;
	status = "okay";
};

/* IMU MPU6050 */
&i2c1 {
	pinctrl-0 = <&i2c1_scl_pb6 &i2c1_sda_pb7>;
	pinctrl-names = "default";
	status = "okay";
	clock-frequency = <I2C_BITRATE_FAST>;

	mpu6050: mpu6050@68 {
		compatible = "invensense,mpu6050";
		reg = <0x68>;
		status = "okay";
		int-gpios = <&gpiob 5 GPIO_ACTIVE_HIGH>;
	};
};

/* Motor PWM: TIM3 CH1-CH4 on PA6, PA7, PB0, PB1 */
&timers3 {
	st,prescaler = <0>;
	status = "okay";

	motor_pwm: pwm {
		compatible = "st,stm32-pwm";
		status = "okay";
		pinctrl-0 = <&tim3_ch1_pwm_out_pa6
			     &tim3_ch2_pwm_out_pa7
			     &tim3_ch3_pwm_out_pb0
			     &tim3_ch4_pwm_out_pb1>;
		pinctrl-names = "default";
		#pwm-cells = <3>;
	};
};

/* Battery voltage ADC on PA5 (ADC1_IN5) */
&adc1 {
	pinctrl-0 = <&adc1_in5_pa5>;
	pinctrl-names = "default";
	status = "okay";
	#address-cells = <1>;
	#size-cells = <0>;

	channel@5 {
		reg = <5>;
		zephyr,gain = "ADC_GAIN_1";
		zephyr,reference = "ADC_REF_INTERNAL";
		zephyr,acquisition-time = <ADC_ACQ_TIME_DEFAULT>;
		zephyr,resolution = <12>;
	};
};

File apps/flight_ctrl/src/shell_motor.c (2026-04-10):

/* SPDX-License-Identifier: Apache-2.0 */

#include <app/shell.h>
#include <app/core/mixer.h>
#include <zephyr/drivers/pwm.h>

/* TIM3 PWM controller */
static const struct device *pwm_dev;

/* Channel mapping: motor index → TIM3 channel (1-based) */
#define MOTOR_FR_CH 1 /* TIM3_CH1 = PA6 */
#define MOTOR_BL_CH 2 /* TIM3_CH2 = PA7 */
#define MOTOR_BR_CH 3 /* TIM3_CH3 = PB0 */
#define MOTOR_FL_CH 4 /* TIM3_CH4 = PB1 */

static const uint32_t motor_ch[] = {
	[MOTOR_FR] = MOTOR_FR_CH,
	[MOTOR_FL] = MOTOR_FL_CH,
	[MOTOR_BR] = MOTOR_BR_CH,
	[MOTOR_BL] = MOTOR_BL_CH,
};

#define PWM_PERIOD_NS PWM_USEC(50) /* 20 kHz = 50 us period */

int shell_motor_init(void)
{
	pwm_dev = DEVICE_DT_GET(DT_NODELABEL(motor_pwm));
	if (!device_is_ready(pwm_dev)) {
		return -ENODEV;
	}

	for (int i = 0; i < 4; i++) {
		pwm_set(pwm_dev, motor_ch[i], PWM_PERIOD_NS, 0, 0);
	}
	return 0;
}

void shell_motor_set(uint16_t duty[4])
{
	for (int i = 0; i < 4; i++) {
		uint32_t pulse_ns = (uint32_t)duty[i] * PWM_PERIOD_NS /
				    MAX_THROTTLE;
		pwm_set(pwm_dev, motor_ch[i], PWM_PERIOD_NS, pulse_ns, 0);
	}
}

void shell_motor_all_off(void)
{
	for (int i = 0; i < 4; i++) {
		pwm_set(pwm_dev, motor_ch[i], PWM_PERIOD_NS, 0, 0);
	}
}

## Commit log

2024-07-25 feat(drivers): Create custom joystick driver
    Create custom joystick with compatible the MicroBlue application.
    [pwm-motors.yaml]
2024-07-26 refactor(DTS): Rename the PWM nodes
2024-07-28 docs(SCH/PCB): Add electrical schematic and PCB layout
    [BOM.csv, minidrone.kicad_pcb, minidrone.kicad_sch]
2024-08-10 test(hardware): Light the LEDs with PWM controller.
2024-08-10 fix(PCH/PCB): Programming pins and motor pins definition.
    Correct the programming TX/RX connection.
    Update the motor net-names due to the design changed.
    [minidrone.kicad_pcb, minidrone.kicad_sch]
2024-08-22 docs(SCH/PCB): Update the PCB design to v2.
    The v1's handmade version is too heavy.
    - Remove the STM32 blue pill board.
    - Using the STM32F103CBT6 to make sure the ROM size enough.
    - Design the PCB as the drone's frame.
    [BOM.csv, minidrone.kicad_pcb, minidrone.kicad_sch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]
2024-09-29 fix(SCH/PCB): The reset button no function
    [minidrone.kicad_pcb, stm32_dev.kicad_sch]
2026-01-01 fix(circuit): fix the battery series or parallel circuits
    - Correct the invert connection on SW3
    - Correct the silkscreen for voltage selection
    [minidrone.kicad_pcb, minidrone.kicad_sch, stm32_dev.kicad_sch]
2026-01-01 fix(circuit): add mounting hole
    [minidrone.kicad_pcb, minidrone.kicad_sch]
2026-03-24 chore: add stm32_minidrone board
    - add stm32_minidrone board
    - remove test code
    [pwm-motors.yaml]
2026-03-24 docs(design): add VSDD Phase 1 specification suite
    Replace informal BOM.md and feature.md with comprehensive spec documents
    following the Verified Spec-Driven Development (VSDD) methodology.
    Specs cover hardware, features, protocols (MicroBlue BT), mechanical,
    safety, performance, behavioral contracts, and verification architecture.
    Includes adversarial review fixes for motor mixer, voltage divider,
    PWM resolution, PID controller count, and failsafe consistency.
2026-03-24 fix(board): add full_name to board.yml and driver stubs
    board.yml requires full_name alongside name per Zephyr board schema.
    Add empty Kconfig and CMakeLists.txt in drivers/ to unblock builds.
2026-03-24 feat(core): add pure core module headers
    Define interfaces for all pure core modules per VSDD spec:
    - state_machine.h: 3-mode FSM with event processing
    - pid.h: PID controller with anti-windup
    - mixer.h: X-quad motor mixing with clamping
    - input_mapper.h: joystick and slider-to-gain mapping
    - battery.h: ADC conversion and hysteresis level detection
    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
2026-03-24 feat(core): implement pure core modules
    Minimal TDD implementations for all pure core modules:
    - state_machine: 3-mode FSM with debounce, cutoff, and tilt handling
    - pid: P/I/D with integrator windup clamp at +/-500
    - mixer: X-quad motor mixing, output clamped to [0, MAX_THROTTLE]
    - input_mapper: joystick center=512→0, slider-to-gain with clamping
    - battery: ADC-to-mV conversion (30K/20K divider), hysteresis levels
    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
2026-03-24 test(core): add Ztest suite and abstract input interface
    VSDD Phase 2: 55 tests across 7 suites (state_machine, pid, mixer,
    input_mapper, battery, parser, calibration) all passing on native_sim.
    Update specs to decouple input from MicroBlue:
    - Add abstract drone_cmd_t interface in behavioral.md
    - Add input/telemetry backend interfaces
    - Update verification purity boundary map
    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
2026-03-24 fix(core): address adversarial review findings
    VSDD Phase 3/4 fixes from adversarial code roast:
    - state_machine: carry calibration_valid/last_disarm_ms in sm_result_t;
    add sm_apply() helper; cutoff in Calibrate transitions to Diag;
    add REPORT_LOWBATT on critical; invalid mode returns MOTORS_OFF
    - calibration: use int64_t for sum/variance to prevent overflow
    - pid: guard derivative term with dt > 1e-6f to prevent Inf/NaN
    - mixer: add isfinite() guard in clamp to prevent UB on NaN input
    - battery: allow recovery from CUTOFF when voltage rises
    - microblue_parser: reject oversized IDs instead of truncating
    - input_mapper: clamp joystick raw input to [0, JOYSTICK_MAX]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
2026-03-24 test(core): harden tests from adversarial review
    - Fix tautological PID zero-error test; add sign convention test
    - Add near-zero dt safety test for PID derivative
    - Assert exact ADC conversion value (8250 mV) instead of fuzzy range
    - Mixer negative test asserts specific expected duty values
    - Parser oversized ID test asserts unconditional rejection
    - Add joystick out-of-range clamp test
    - Add battery cutoff recovery test
    - Verify calib_ok sets calibration_valid in result
    59 tests total, all passing on native_sim.
    [main.c]
2026-03-24 fix(parser): reject non-printable ASCII in ID and VALUE fields
    Fuzz testing (libFuzzer, 1M iterations) found that null bytes in ID or
    VALUE fields caused strlen() to return 0 on seemingly valid messages,
    violating VP-15 (valid output has non-empty id and value).
    Validate that all ID and VALUE bytes are printable ASCII (0x20-0x7E)
    before accepting the message.
2026-03-24 test(verify): add CBMC proof harnesses and libFuzzer harness
    VSDD Phase 5 formal hardening artifacts:
    - tests/fuzz/fuzz_parser.c: libFuzzer harness for VP-14..VP-17
    - tests/cbmc/proof_pid.c: VP-06 (windup), VP-08 (no overflow)
    - tests/cbmc/proof_mixer.c: VP-07/VP-21 (clamped), VP-22 (no negative)
    - tests/cbmc/proof_battery.c: VP-10 (no overflow), VP-18 (hysteresis)
    - tests/cbmc/proof_input_mapper.c: VP-09 (center=0), VP-23 (gain bounds)
    - tests/cbmc/proof_parser.c: VP-14..VP-17 (parser safety)
    Fuzzer ran 1M iterations with ASan+UBSan, 0 crashes.
    CBMC harnesses ready for when cbmc is installed.
    [proof_battery.c]
2026-03-29 chore: pin Zephyr to v4.1.0 release
    Use a stable tagged release instead of tracking main to ensure
    reproducible builds.
2026-03-29 fix(board): rewrite DTS and defconfig to match KiCad schematic
    Align the device tree with the actual Rev 1 PCB pin mapping:
    - Add PA0-PA3 status LEDs, PC13 power LED with proper aliases
    - Route ADC to PA5 (ADC1_IN5) for battery sensing
    - Route TIM3 CH1-CH4 to PA6/PA7/PB0/PB1 for motor PWM
    - Add MPU6050 I2C child node on I2C1 (PB6/PB7)
    - Set USART3 (PB10/PB11) to 38400 baud for HM-13 Bluetooth
    - Add bt-uart alias for runtime device lookup
    - Remove unused SPI, USB, I2C2 peripherals
    - Enable I2C, PWM, ADC, sensor, and watchdog in defconfig
    [stm32_minidrone.dts]
2026-03-29 fix(core): correct battery voltage divider and calibration threshold
    - Update voltage divider ratio from 0.4 (30K/20K) to 0.25 (30K/10K)
    to match actual circuit: formula becomes adc_raw * 13200 / 4095
    - Raise calibration variance threshold from 100 to 10000 to accommodate
    real IMU noise during power-on with shared 3.3V rail (see HW-08)
    - Update CBMC proof assertion bound to 14000 mV for new formula
    [battery.h, proof_battery.c]
2026-03-29 feat(core): add effectful shell module interfaces
    Add shell.h defining the hardware abstraction layer between the pure
    core logic and Zephyr drivers (BT, IMU, motor, battery, LED).
    Each module is Kconfig-gated; disabled modules compile as no-op stubs.
2026-03-29 feat(app): add flight controller application with shell modules
    Add the main Zephyr application implementing the full flight controller
    data flow: BT command polling, IMU calibration, PID control loop at
    500 Hz, motor mixing, battery monitoring with hysteresis, and telemetry.
    Shell modules:
    - shell_bt: HM-13 UART RX (ISR ring buffer) + TX, MicroBlue protocol
    - shell_imu: MPU6050 via Zephyr sensor API
    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
2026-03-29 docs(design): add hardware issues tracker for Rev 1 PCB
    Document 13 known hardware issues found during board bring-up:
    - BLOCKING: missing MOSFET gate pull-down resistors (HW-01)
    - Circuit: reverse polarity, overcurrent, LC filter, gate resistors, ESD
    - Power: IMU/BT power sequence, inefficient LDO
    - EMI: BT/IMU placement interference
    - Mechanical: weight budget (74g, target <50g), power switch, BOOT0
2026-04-10 refactor(design): reorganize gen1 files into design/gen1/
    Move spec, kicad, and 3d_models under design/gen1/ to
    prepare for gen2 design alongside gen1 in the same repo.
    Rename minidrone_kicad to kicad.
    [BOM.csv, minidrone.kicad_pcb, minidrone.kicad_sch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]
2026-04-10 docs(design): add gen2 drone specification
    Modular architecture: STM32H743VIH6 core module (40x25mm)
    with castellated pads, drone-specific carrier board (50x50mm).
    - 2S/3S LiPo with per-cell monitoring via JST-XH balance port
    - ICM-42688-P IMU, BMP390 baro, VL53L5CX ToF, PMW3901 OF
    - ELRS 2.4GHz primary control, BLE 5.0 config/OTA
    - Bidirectional DSHOT300 with BlueJay ESC for RPM telemetry
    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
2026-04-11 docs(design): update gen2 to 3S/1404 with GPS and camera
    Finalize gen2 spec on single 3S configuration with 1404
    4500KV motors, CNHL 850mAh battery, and removable module
    connectors.
    - Replace 1204 motors with 1404 4500KV (800g total thrust)
    - Remove 2S config; 3S only (CNHL MiniStar 850mAh 70C)
    - AUW 141g, T/W 5.7:1, hover time ~26 min
    - Add JST-GH GPS connector (u-blox M10, removable)
    - Add JST-GH + VBAT camera/VTX connector (removable)
    - Fix power trace widths (copper pour for battery rail)
    - Update XT30 to XT60 for main battery connector
    - 100g payload capacity at T/W 3.3:1
2026-04-11 fix(design): remove stale charger references from gen2
    USB-C function listed "battery charging" and safety ESD
    table referenced "Charger IC handles OVP", but there is
    no onboard charger — external balance charger only.
2026-04-11 docs(design): add auto-land, MCUboot, BLE shell, MicroSD
    - Sensor load switch (TPS22918) for controlled power
    sequence; fixes Gen 1 HW-08
    - Auto-land on ELRS failsafe when altitude >= 2m
    (descend 0.5 m/s with position hold)
    - MCUboot dual-bank swap with automatic rollback on
    failed OTA update
    - Zephyr shell over BLE NUS for runtime command line
    (PID tuning, diagnostics, config)
    - MicroSD blackbox via SDMMC1 4-bit SDIO, FAT32 CSV
    files readable directly on any PC
    - Arm LED spec reserved (WS2812B voltage TBD)
